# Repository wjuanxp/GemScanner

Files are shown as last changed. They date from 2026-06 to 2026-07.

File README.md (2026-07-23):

# GemScanner

A gemstone **outline scanner**. A telecentric lens and a machine-vision camera image a
backlit gemstone on a motorized rotary stage; the silhouettes captured around a full
revolution are fused into a watertight 3-D mesh by **shape-from-silhouette** (visual
hull). The result is an `.stl` you can measure, catalogue, or 3-D print.

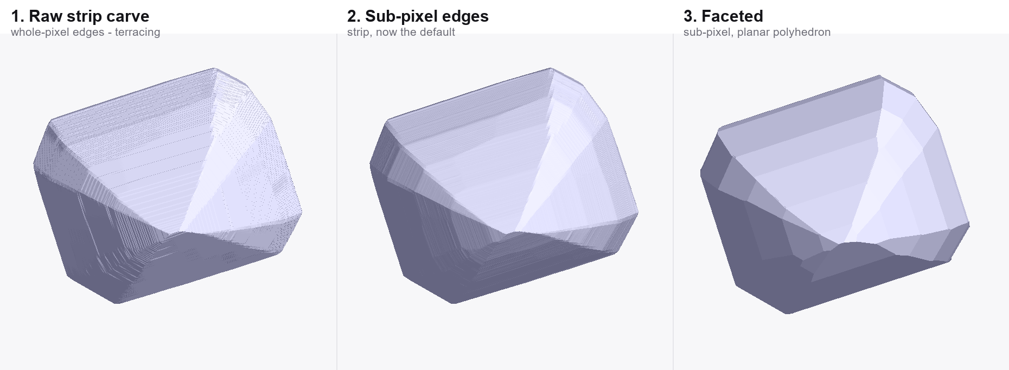
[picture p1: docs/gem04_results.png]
Three reconstructions of the same gem: raw strip carve with terracing, the sub-pixel-edge default with the terracing gone, and the faceted polyhedron


*The same gem04 scan reconstructed three ways. **Left:** the raw per-row strip carve
shows horizontal "strike line" terracing — a reconstruction artifact, not real
geometry. **Middle:** [sub-pixel edge localisation](#sub-pixel-edge-localisation)
(now the default) places each silhouette edge on its intensity crossing instead of
the nearest whole pixel, removing the artifact at its source. **Right:** the
[faceted method](#reconstruction-methods) fits the silhouettes into a watertight
planar polyhedron.*

## How it works

1. A collimated backlight makes the gem a dark silhouette against a bright field.
2. The stage rotates the gem through 360°, capturing ~180 views.
3. Each image row becomes a horizontal cross-section carved by intersecting the
   silhouette strips from every view (the visual hull).
4. The cross-sections are lofted (or marching-cubed) into a closed mesh and exported.

## Highlights

- **Pure-Python reconstruction core** — no hardware needed to reconstruct an existing
  scan or to run the full test suite (synthetic cameras stand in for the rig).
- **PySide6 GUI** — a guided per-gem wizard (mount → align → calibrate → scan →
  reconstruct) with live preview, exposure/gain control, and a reconstruction-method
  picker.
- **Selectable reconstruction methods** — trade speed for surface quality, from a fast
  raw visual hull to an anti-aliased volumetric hull (see below).
- **Faceted reconstruction** — for step-cut / faceted stones, an unsupervised
  facet-plane recovery (`method="facet"`) that fits the silhouette support function
  into a watertight polyhedron of planar facets, girdle ring included.
- **Swappable camera backends** — `gentl` (Harvesters/GenICam), `baumer` (neoAPI),
  `opencv` (USB), or `mock` — a one-line config change.
- **ESP32-C6 motion firmware** — a USB-CDC line protocol driving a 5-phase stepper
  (`firmware/`).

## Repository layout

| Path | What |
|---|---|
| `gemscanner/reconstruction/` | Visual hull, soft hull, faceted-plane fit, mesh lofting, de-terracing |
| `gemscanner/vision/` | Silhouette extraction |
| `gemscanner/gui/` | PySide6 app (wizard, preview, panels, worker thread) |
| `gemscanner/camera/` | Camera backends + factory (`gentl`/`baumer`/`opencv`/`mock`) |
| `gemscanner/motion/` | Rotary stage client speaking the firmware protocol |
| `gemscanner/acquisition/` | Step-and-settle scan controller, pre-scan FoV check |
| `gemscanner/calibration/` | Rotation-axis probing |
| `gemscanner/synthetic/`, `gemscanner/testing/` | Synthetic ellipsoid scans + fakes |
| `firmware/` | ESP-IDF ESP32-C6 motion controller (see `firmware/README.md`) |
| `docs/` | Design specs, camera notes, usage |

## Install

Targets **Python 3.12** on Windows (Open3D has no 3.13 wheel yet).

```powershell
py -3.12 -m venv .venv
.\.venv\Scripts\python -m pip install -e ".[dev]"
```

Runtime dependencies: `numpy`, `scipy`, `opencv-python`, `trimesh`, `open3d`,
`scikit-image`, `pyserial`, `pyyaml`, `harvesters`, `PySide6`. The GenTL camera backend also needs a
vendor `.cti` producer installed on the machine (e.g. Baumer's `bgapi2_gige.cti`).

## GUI

The primary interface. It reads `project.yaml` (camera backend, serial port, mm/px,
steps-per-rev, and the list of gems):

```powershell
.\.venv\Scripts\python -m gemscanner.cli gui          # or: gemscanner gui
```

Work through the left-hand wizard for each gem: **Mount → Align lighting → Holder mask
→ Calibrate axis → Scan → Reconstruct**. Pick a method in the **Reconstruction**
dropdown before clicking *Reconstruct*; the result is written to
`scans/<gem>/gem.stl`. Reconstruction reads the already-captured frames, so you can
scan once and re-reconstruct with different methods to compare.

## Reconstruction methods

The horizontal "strike lines" (terracing) sometimes seen on a raw scan are an artifact
of carving each image row independently — not real gem geometry. These options remove
them while preserving genuine facet edges (all measured on a real 17 µm/px scan):

| GUI choice | `ReconstructionParams` | What it does | Terracing¹ | Cost |
|---|---|---|---|---|
| Fast (visual hull) | *(defaults)* | Raw per-slice visual hull | baseline | fast |
| Smooth edges *(recommended)* | `edge_median_rows=9` | Median-smooths the silhouette edge per view (image space) | ≈ −80% | fast |
| Smooth surface | `axial_median_rows=9` | Median-smooths the ring radius field along z (mesh space) | ≈ −85% | fast |
| High accuracy | `method="soft_hull"` | Anti-aliased volumetric visual hull + marching cubes | ≈ −70%, sharper facets | minutes |
| Faceted gem (planar) | `method="facet"` | Fits the support function into planar facets → watertight polyhedron | n/a² | seconds |

¹ Reduction of the horizontal-band artifact on a real 17 µm/px scan; larger median
windows remove more (edge window 15 reaches ≈ −96%).

### Sub-pixel edge localisation

The options above *denoise* the terracing after the fact. `subpixel_edges`
(**on by default**; CLI: `--no-subpixel-edges` for a whole-pixel baseline, GUI:
the *Sub-pixel edges* checkbox) attacks its source instead: rather than snapping
each silhouette edge to the nearest whole column, it places the edge where that
row's intensity profile crosses the threshold, by linear interpolation between
the bracketing pixel pair. Edge position becomes continuous instead of quantised
to 17 µm, so rows whose true edges differ by a fraction of a pixel stop reporting
the same value.

Measured on `scans/gem04` (`holder_mask_rows=705`, 30 views):

| | whole-pixel | sub-pixel |
|---|---|---|
| per-row edge roughness (median \|d²edge/dz²\|) | 12.62 µm | **2.18 µm** (−83%) |
| distinct edge values per view | 217 of 378 rows | 374 of 378 rows |
| mean edge shift | — | +0.43 µm |

The shift is negligible because real backlit edges are anti-aliased and Otsu
lands mid-ramp, so the two crossings move symmetrically. (A hard *synthetic*
step has no ramp and does shift ~half a pixel per side — synthetic accuracy
figures are not comparable across the flag.) Whole-slice results move very
little: `strip` volume +0.5%, `facet` +0.04%, both still watertight; `facet`
recovers 208 → 232 planes.

On by default since the gem04 strip + facet sub-pixel meshes cleared the
`method="facet"` v2.3 visual sign-off gate. Ignored by `method="soft_hull"`,
which carves from a distance transform instead of spans.

² The faceted method doesn't carve per-slice rings, so terracing doesn't arise — it
recovers the facet planes directly.

Edge/axial median use rank-rejection of per-row outliers, so facets stay crisp;
measured impact on volume is ≤ +0.24% and on bounding dimensions effectively zero.
The soft hull is the most accurate (synthetic-ellipsoid volume error −0.8% vs −2.7%
for the raw hull) and produces a watertight single-body mesh; it requires
`scikit-image`.

The **faceted** method is for genuinely faceted stones (step cuts, brilliants). Instead
of carving cross-sections it detects each facet's azimuth from the slice-polygon edges,
segments the per-view support function `H(z)` into planar tiers, recovers the girdle
band, and assembles the resulting half-spaces into a single watertight polyhedron of
flat facets — in seconds, with no soft-hull seed. On the gem04 reference scan it
recovers 56 facets (including the faceted girdle ring) at 5 µm median per-facet fit,
with bounding-box extents within 16/40/77 µm (X/Y/Z) of the visual-hull mesh. It is
best on clean step/brilliant cuts; rounded cabochons should use one of the hull methods.
Requires `scipy`.

## CLI

```powershell
# Reconstruct a mesh from an existing scan dataset (no hardware)
.\.venv\Scripts\python -m gemscanner.cli reconstruct scans\gem01 -o gem.stl

# Choose the method, mask the pedestal rows, and use sub-pixel edges
# (this is the gem04 faceted recipe as a one-liner)
.\.venv\Scripts\python -m gemscanner.cli reconstruct scans\gem04 -o gem.stl `
    --method facet --holder-mask-rows 705 --subpixel-edges

# View a mesh in an interactive Open3D window
.\.venv\Scripts\python -m gemscanner.cli view gem.stl

# Full bench scan: config -> prescan -> capture 360 deg -> reconstruct -> gem.stl
.\.venv\Scripts\python -m gemscanner.cli scan -c config.example.yaml -o scans\gem01
```

## Configuration

`config.example.yaml` (for the `scan` CLI) and `project.yaml` (for the GUI) select the
camera backend, serial port, scan parameters, and calibration file. For the legacy
Baumer EXG50 GigE camera use `camera_backend: gentl` with a `cti_path` to a GenTL
producer; neoAPI (`baumer`) only supports the newer CX/X families. Swapping to a USB
camera is a one-line change to `opencv`.

## Tests

```powershell
.\.venv\Scripts\python -m pytest -q
```

All orchestration, protocol, reconstruction, and GUI logic is host-tested in-process
via `FakeFirmware` (the firmware protocol contract), `MockCamera`, and `SceneCamera`
(which links the fake motion angle to a rendered ellipsoid silhouette). Real serial
I/O, the OpenCV/Baumer/GenTL cameras, and the Open3D window are **bench-verified** on
hardware.

## Bench bring-up

With the camera and collimated backlight aligned, the stage/driver/ESP32 powered, and a
`calibration.json` (axis column, mm/px, steps-per-rev) produced from the calibration
routines, run the GUI wizard or the `scan` CLI. The pre-scan FoV check aborts (naming
the clipping angle) if the gem leaves the frame at any rotation; otherwise it captures
the revolution, reconstructs, and writes a watertight `gem.stl`. Compare the
bounding-box extents against caliper measurements within the calibrated tolerance.

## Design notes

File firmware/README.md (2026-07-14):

# GemScanner Firmware (ESP32-C6)

Motion-control firmware for the gemstone outline scanner. Runs on a **Waveshare
ESP32-C6-LCD-1.47** and drives the SURUGA SEIKI KRW06360 rotary stage (Oriental
Motor 5-phase stepper via an **ADB-5331A** driver) under a line-based USB-CDC
command protocol, so the host PC can run step-and-settle scans.

Built with **ESP-IDF 5.4**.

## Architecture

Pure logic is isolated from hardware so it can be unit-tested on a PC:

| Path | Responsibility | Tested |
|---|---|---|
| `components/command_parser` | ASCII line → `command_t` | host (gcc/ctest) |
| `components/motion_math` | degrees↔microsteps, angle wrap | host |
| `components/ramp` | trapezoidal step-interval planner | host |
| `components/fmt_num` | integer → comma-grouped string (`35,000`) | host |
| `main/stepper.c` | GPTimer STEP/DIR pulse generation w/ ramp | bench |
| `main/usb_cdc.c` | USB Serial/JTAG line read/write | bench |
| `main/controller.c` | command dispatch + state machine | bench |
| `main/status_display.c` | RGB LED + ST7789 LCD (LVGL) status | bench |
| `main/app_main.c` | init order + run loop | bench |

These `components/*` modules contain **no ESP-IDF headers** and are compiled
both into the firmware and into the host test harness (`host_test/`).

## Command protocol

Line-based ASCII, terminated by `\n`, `\r`, or `\r\n`. Replies are `\n`-terminated.
A move command replies `OK` immediately, then `READY` after the move completes and
the settle delay elapses.

| Command | Meaning | Immediate | Deferred |
|---|---|---|---|
| `STEP <n>` | move `n` microsteps, signed (+ = DIR active) | `OK` | `READY` |
| `MOVEDEG <x>` | move `x` degrees (float) | `OK` / `ERR nores` | `READY` |
| `SETV <v>` | max speed, microsteps/s (>0) | `OK` / `ERR badarg` | — |
| `SETACC <a>` | acceleration, microsteps/s² (>0) | `OK` / `ERR badarg` | — |
| `SETSETTLE <ms>` | settle delay, ms (≥0) | `OK` / `ERR badarg` | — |
| `SETRES <n>` | microsteps per 360° (>0) | `OK` / `ERR badarg` | — |
| `HOME` | zero the logical angle (no motion) | `OK` | `READY` |
| `STATUS` | query | `STATUS angle=<deg> steps=<n> state=idle v=<> a=<> settle=<ms> res=<n>` | — |

Unknown verb → `ERR unknown`. Bad/missing argument → `ERR badarg`.

**`steps-per-360°` is never hardcoded.** It is `motor step angle × driver microstep ×
stage gear ratio` and must be sent at runtime with `SETRES` (the PC calibrates it).
Until `SETRES` is sent, `MOVEDEG` returns `ERR nores` and the reported/displayed
`angle` stays `0.00` (steps still track).

Defaults at boot: `v=4000`, `a=20000`, `settle=150`, `res=0`, `pos=0`.

## Wiring

### Stepper driver (1-pulse mode)
The ADB-5331A must be set to **1-pulse mode** (PULSE + DIRECTION). Its inputs are
opto-isolated and expect ~5 V, so drive them through a **3.3 V → 5 V buffer /
level-shifter** — do not wire the ESP32 GPIOs straight into the driver.

| ESP32-C6 | Signal | → buffer → ADB-5331A |
|---|---|---|
| GPIO1 | STEP (pulse) | PULSE+ |
| GPIO2 | DIR | DIR+ |
| GPIO3 | ENABLE | AWO/ENABLE+ |
| GND | common | input commons |

Active levels and the STEP pulse width are in `main/pins.h` (`DIR_ACTIVE_LEVEL`,
`ENABLE_ACTIVE_LEVEL`, `STEP_PULSE_US`). Verify the driver's input current-limit
resistor and minimum pulse width against the ADB-5331A datasheet. (HOME has no
sensor yet — it only zeroes the logical angle.)

### On-board peripherals (no external wiring)

Both indicators share one **per-state palette** so they always agree. The state
is one of four values (`disp_state_t`); the LCD shows a friendlier word for each:

| State (`disp_state_t`) | LCD word | Accent colour | Meaning |
|---|---|---|---|
| `ST_DISCONNECTED` | **OFFLINE** | muted blue `#5A6B8C` | no host link |
| `ST_IDLE` | **READY** | green `#22C55E` | waiting for a command |
| `ST_MOVING` | **ROTATING** | amber `#F5A623` | stage in motion |
| `ST_SETTLING` | **SETTLING** | cyan `#22D3EE` | holding to stabilise |

(The USB `STATUS` reply is separate and still reports `state=idle`; the words
above are display-only.)

- **RGB LED** (WS2812, GPIO8): lit in the accent colour of the current state
  (blue / green / amber / cyan above), dimmed for comfortable brightness. *Note:*
  this board's LED takes **RGB** order while `led_strip`'s WS2812 model emits GRB,
  so `led_set()` swaps R↔G.
- **LCD** (ST7789, 172×320, SPI: MOSI=6 SCLK=7 CS=14 DC=15 RST=21, backlight=22):
  a minimalist **dark-theme** status screen (`status_display.c`) — a full-width
  accent bar and dot at the top, the large colour-coded **state word** (hero), a
  hairline divider, then `angle` (`142.50°`) and comma-grouped `steps` (`35,000`)
  as value + caption pairs, centred on the near-black canvas. Uses the Montserrat
  20/28 fonts (enabled in `sdkconfig.defaults`; 14 is on by default). Three
  settings were needed for this panel: `swap_bytes = true` (RGB565 byte order —
  without it text shows a colour fringe), `esp_lcd_panel_set_gap(panel, 34, 0)`
  (the 172-wide panel's RAM offset), and the backlight on **GPIO22 via LEDC PWM**
  at `LCD_BL_DUTY_PCT` (default 50%).

## Build, flash, monitor

Activate ESP-IDF 5.4 first (this install lives at `D:\ESP32`):

```powershell
& 'D:\ESP32\idf\v5.4\esp-idf\export.ps1'
cd 'D:\CodingProject\GemScanner\firmware'
idf.py set-target esp32c6     # once
idf.py build
idf.py -p COMx flash monitor  # COMx = the board's port; Ctrl+] exits monitor
```

The first build downloads the managed components (`lvgl 9.3`, `esp_lvgl_port 2.8`,
`led_strip 2.5`) — it needs network and is slower.

### Talking to it
In `idf.py monitor` there is **no local echo** — you won't see what you type, only
the board's replies. Press Enter (sends CR; the firmware accepts CR/LF/CRLF). Try:

```
SETRES 50000
STATUS
STEP 12500      → OK … READY  (stage turns ~90° if res≈50000)
MOVEDEG 45      → OK … READY
```

If replies are garbled by interleaved log bytes, set the console off USB:
`idf.py menuconfig → Component config → ESP System Settings → Channel for console
output → None` (or UART0), then rebuild — the protocol then owns the USB link.

## Host unit tests (no hardware)

```bash
cd firmware/host_test
cmake -S . -B build -G Ninja
cmake --build build
ctest --test-dir build --output-on-failure
```

Covers `command_parser`, `motion_math`, `ramp`, and `fmt_num`.

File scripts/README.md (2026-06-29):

# Bench scripts

Guided bring-up / calibration scripts. Run each from the repo root with the venv:

```powershell
.venv\Scripts\python.exe scripts\<name>.py --help
```

They all read `config.example.yaml` (`-c` to override) and read/write the
`calibration.json` named by `calibration_path` in that config.

## Recommended order

1. **Motion** — confirm the stage turns:
   ```powershell
   .venv\Scripts\python.exe scripts\smoke_motion.py --res 50000
   ```
2. **Camera** — grab a frame, eyeball exposure:
   ```powershell
   .venv\Scripts\python.exe scripts\grab.py -e 470000 -o grab.png ; Invoke-Item grab.png
   ```
3. **steps_per_rev** — empirical is most reliable (command N steps, measure degrees):
   ```powershell
   .venv\Scripts\python.exe scripts\calibrate_steps.py --empirical 50000 360
   # or directly:        --value 50000
   # or computed:        --compute 500 10 18     (motorSteps microstep gear)
   ```
4. **mm_per_px** — from a gauge of known length imaged by the camera:
   ```powershell
   .venv\Scripts\python.exe scripts\calibrate_scale.py --px 1000 --mm 28.8 --write
   ```
5. **axis_column** — fit the rotation axis from silhouette centroids:
   ```powershell
   .venv\Scripts\python.exe scripts\calibrate_axis.py -n 12 --write
   ```
6. **FoV check** — confirm the gem never clips over a revolution:
   ```powershell
   .venv\Scripts\python.exe scripts\check_fov.py -n 12
   ```

After 3-5, `calibration.json` holds `steps_per_rev`, `mm_per_px`, `axis_column`
(+ `axis_tilt_rad=0`, `eccentricity_mm`). Then run the full pipeline:

```powershell
.venv\Scripts\python.exe -m gemscanner.cli scan -c config.example.yaml -o scans\gem01
.venv\Scripts\python.exe -m gemscanner.cli view scans\gem01\gem.stl
```

## Notes
- Only one app can hold the GigE camera at once - close Camera Explorer before running these.
- `calibrate_steps`/`calibrate_scale`/`calibrate_axis` use `--write` to persist into
  `calibration.json`; without it they just print the value.
- Long camera exposure (e.g. 470 ms with no dedicated light) makes scans slow; lower it
  once the collimated backlight is installed.

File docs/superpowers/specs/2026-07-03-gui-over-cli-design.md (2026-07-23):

# GemScanner GUI — Design Spec

**Date:** 2026-07-03
**Status:** Approved (brainstorming), pending implementation plan
**Depends on:** Plan A (reconstruction core), Plan B (firmware), Plan C (hardware integration) — all merged to `main` and bench-verified 2026-07-03.

## 1. Purpose & Scope

A PySide6 desktop application that turns the current edit-YAML-and-rerun-scripts workflow into an
interactive, guided process. The headline capabilities the user asked for:

- **Live lighting/alignment preview** — see the camera frame while positioning the gem and backlight.
- **Interactive exposure/gain tuning** — adjust and see the effect immediately.
- **Easier batch scanning** — a guided queue of gems, one operator loop.

The GUI **wraps** existing library code. It does not reimplement reconstruction, calibration, or scan
orchestration. The existing `reconstruct` / `view` / `scan` CLI commands and the `scripts/` bring-up
tools remain fully working; the GUI is additive.

### Out of scope (YAGNI)

- Scan-history database or re-scan browser.
- Multi-user / remote / web access.
- A camera streaming API — live preview is polled `grab()`.
- Changes to the unused `OpenCvCamera.grab` / neoAPI `BaumerCamera` paths.

## 2. Architecture — Three Layers

### a. Service layer (Qt-free, unit-testable) — `gemscanner/gui/session.py`

A `ScanSession` owns exactly one opened camera and one stage, and exposes coarse operations that reuse
existing code:

- `grab()` — one frame.
- `analyze_frame(frame, threshold, holder_mask_rows)` — returns silhouette mask + `min/max/mean` +
  intensity histogram + FoV/eccentricity status. Built on existing `vision.silhouette.extract_silhouette`
  and `acquisition.prescan`.
- `calibrate_axis(n_probe, progress, cancel)` — rotates a revolution, fits `axis_column`.
- `run_scan(params, progress, cancel)` — drives the scan, writes the dataset.
- `reconstruct(out_dir, holder_mask_rows, smooth, method, edge_median_rows, axial_median_rows, subpixel_edges)`
  — builds + smooths the mesh, returns watertight/extents. `subpixel_edges` (default `True`, added
  2026-07-23) places each silhouette edge on its intensity crossing instead of the nearest whole pixel.

This layer has no Qt imports and is fully testable headless with `MockCamera` / `SceneCamera` +
`FakeFirmware`.

### b. Project model — `gemscanner/gui/project.py`

Dataclasses:

- `GemJob`: `name`, `holder_mask_rows`, `axis_column`, optional `exposure_us` / `gain` overrides,
  `out` (output dir).
- `Project`: shared camera settings + serial config + project-level `mm_per_px` and `steps_per_rev`
  (these carry across gems on the same pedestal/motor), plus an ordered `gems: [GemJob, ...]` list.

Load/save to `project.yaml`, which is a **superset of the current `ScannerConfig` schema**. A single-gem
project therefore remains runnable by the existing `scan` CLI, and `calibration.json` semantics are
preserved.

### c. Qt UI layer — `gemscanner/gui/app.py` + widgets

- `LivePreviewWidget` — a `QGraphicsView` showing the frame with overlays:
  - Silhouette (Otsu-threshold) tint, so the operator sees exactly what reconstruction will "see"
    (reveals refracted-light leak holes, edge blur, uneven backlight). Threshold selectable Otsu/manual.
  - Draggable horizontal **holder-mask line**; everything below is greyed. Sets `holder_mask_rows`.
  - **FoV/eccentricity warning** — red when the silhouette touches an image border or is badly off
    the calibrated axis; green "ready to scan" when clear.
  - **Exposure stats + histogram** panel — live `min/max/mean` and an intensity histogram to confirm
    the gem hits ~0 and the background is bright/uniform.
- `WizardPanel` — the per-gem step sequence (Section 5).
- `QueuePanel` — add / remove / reorder gems.
- `ReconstructionPanel` — how the mesh is built from the silhouettes:
  - A method-preset combo (Fast strip hull / Smooth edges / Smooth surface / High accuracy soft-hull /
    Faceted gem), each mapping to reconstruction kwargs.
  - A **Sub-pixel edges** checkbox (added 2026-07-23, **default checked**) — orthogonal to the preset:
    it applies to the strip and facet methods (soft-hull ignores it), so it sets `subpixel_edges` in
    `selected_kwargs()` independently of the combo choice. `set_subpixel_edges(on)` toggles it and it is
    threaded `ReconstructionPanel → main_window → worker._op_reconstruct → session.reconstruct`.

### Visual style

Modern minimalism with a **dark theme**. Applied via a single Qt stylesheet (QSS) loaded at startup —
no per-widget inline styling. Guidelines:

- Dark neutral background (near-black / dark grey), low-chroma surfaces, one restrained accent color for
  primary actions and the "ready to scan" state.
- Generous spacing, flat controls (no heavy bevels/gradients), minimal borders — separation by spacing
  and subtle surface elevation rather than lines.
- The live preview is the visual focus: the frame sits on the darkest surface so the bright backlit
  silhouette carries the contrast; overlays (silhouette tint, mask line, FoV state) use the accent and a
  warning color sparingly.
- One clean sans-serif type scale; status/stats in a monospace face for legibility of `min/max/mean`.

Style lives in `gemscanner/gui/style.qss` so it can be tweaked without touching widget code.

## 3. Threading

The primary implementation risk. A **single `HardwareWorker` `QThread` is the only owner of the camera
and stage** — this mirrors the physical constraint that only one consumer can hold the GigE camera (and
the single serial port). The UI thread posts commands; the worker executes and emits Qt signals
(`frame_ready`, `progress`, `done`, `error`).

- **Live preview** = the worker polling `grab()` in a loop while idle, downscaling for display, emitting
  at whatever rate the 5 MP EXG50 sustains (a few fps is fine for alignment). It **auto-pauses** during
  moves, scans, and calibration because those run on the same single thread.
- **Cancellation** = a flag checked between scan views and between calibration probes.

No `CameraBackend` change is needed; polled preview works with `MockCamera` / `SceneCamera` for
hardware-free development and testing.

## 4. Required Refactor (small, removes duplication)

- Extract the axis-fit probe loop currently inline in `scripts/calibrate_axis.py:main` into
  `gemscanner/calibration/axis_probe.py` as a callable function with `progress` and `cancel` hooks.
- Add `progress` and `cancel` hooks to `ScanController.run` in
  `gemscanner/acquisition/scan_controller.py`.

`scripts/calibrate_axis.py` and the GUI then call the same `axis_probe` function; the scan path is shared
too. `run_scan_from_config` stays as the CLI entry point, but the GUI drives the finer-grained steps
directly since it already holds the camera and stage open.

## 5. Guided Wizard Flow (per gem)

0. **Connect** (once per session): choose project file, camera backend / exposure / gain, COM port →
   connect; live preview starts.
1. **Mount** — prompt operator to mount the gem → confirm.
2. **Align** — live preview + exposure/gain sliders + histogram. Tune until the gem is solid black
   (`min≈0`), the background is bright and uniform, the silhouette overlay is solid (no leak holes), and
   the FoV indicator is green.
3. **Holder mask** — drag the mask line to the gem/pedestal junction → `holder_mask_rows`.
4. **Calibrate axis** — [Run] rotates one revolution over `n_probe` steps, fits `axis_column`, shows the
   centroid-swing amplitude, with live progress. Writes into the gem's calibration.
5. **Scan** — runs `n_views` with a progress bar and cancel; the preview updates per view.
6. **Reconstruct + smooth** — builds the mesh, reports watertight + extents; [View] opens the Open3D
   viewer in a background window (offscreen render is unavailable on this machine — no EGL headless).
7. **Advance** — prompt "swap to `<next gem>`" → loop back to step 1 for the next queued gem.

## 6. Persistence

`project.yaml`, a superset of the current config schema:

```yaml
camera_backend: gentl
camera: { cti_path: ..., exposure_us: 500, gain: 5, pixel_format: Mono8 }
serial_port: COM3
serial_baud: 115200
mm_per_px: 0.0170          # project-level; carries across gems on the same pedestal/motor
steps_per_rev: 90000       # project-level
gems:
  - name: ruby-01
    holder_mask_rows: 660
    axis_column: 1214
    out: scans/ruby-01
    # optional per-gem exposure_us / gain overrides
  - name: emerald-02
    holder_mask_rows: 705
    axis_column: 1216
    out: scans/emerald-02
```

The GUI reads and writes this file. `calibration.json` semantics (axis_column / mm_per_px /
steps_per_rev / axis_tilt_rad) are preserved for CLI compatibility.

## 7. Error Handling

- Camera-open failure (e.g. GigE camera still held by Baumer Camera Explorer `bexplorer`) → clear
  non-fatal dialog telling the operator to close the other app.
- `StageError` timeouts → non-fatal dialog; the ESP32 reset-on-serial-open quirk is already handled by
  `SerialTransport` (settle + flush after open, fix `a1cba1f`).
- FoV-clip failure at the Scan step blocks scanning with an explicit message ("silhouette clips; re-seat
  the gem").
- Cancel stops between views and leaves the partial dataset flagged.

## 8. Testing

- Service layer (`ScanSession`) and project model (`Project` / `GemJob` load/save) unit-tested headless
  with `MockCamera` / `SceneCamera` + `FakeFirmware`, extending the existing 53-test suite.
- The end-to-end mock scan→reconstruct path (via `SceneCamera`) is reused to test `run_scan` /
  `reconstruct` wiring through the session.
- UI kept thin — logic lives in the tested service layer. Optional `pytest-qt` smoke test for widget
  construction and the mask-line → `holder_mask_rows` binding.

## 9. Dependencies

- New: **PySide6** (Qt for Python). Optional dev dep: `pytest-qt`.
- Existing venv is Python 3.12 (open3d has no 3.13 wheel) — PySide6 has 3.12 wheels.

## 10. Open Questions / Deferred

None blocking. Deferred to future work: scan history, unattended multi-gem (blocked by the physical swap
requirement anyway), and finishing/removing the unused OpenCV/neoAPI camera backends.

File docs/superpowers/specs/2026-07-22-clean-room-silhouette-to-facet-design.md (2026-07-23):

# Clean-room silhouette → faceted-gemstone investigation

Date: 2026-07-22. Scope: a fresh, independent investigation of the
silhouette → faceted-convex-polytope reconstruction problem, run as a
survey-then-bake-off on the gem04 real scan. This is deliberately a
clean-room exercise: the shipped `method="facet"` (v2.3) pipeline is set
aside as a **benchmark to match/beat**, not reused or extended.

## Why this exists

The shipped v2.3 facet pipeline is already merged, signed off on gem04
(56 planes, watertight, 5 µm median facet RMS, extents X+16 / Y+40 / Z+77 µm
vs `gem.stl`) and is structurally free of horizontal strike-lines. The user
asked for a **clean-room investigation** anyway: re-derive the problem from
first principles, survey the method families the literature offers, and
empirically bake off the most promising ones on the real gem04 frames — to
learn whether an independent approach matches, beats, or teaches us something
the shipped one does not (notably the residual Z +77 µm extent gap).

## The data (gem04)

- 180 backlit silhouettes, 2° turntable steps, full 360°.
- **Orthographic** projection (confirmed: `coords.column_to_projection` is a
  pure linear `mm_per_px` scale, no perspective divide). This is the linchpin
  assumption for the entire support-function / dual-convex framework.
- Known calibration: `mm_per_px`, per-row `axis_column` (+ small `axis_tilt`),
  per-frame angle. `holder_mask_rows = 705` masks the pedestal post (rig
  calibration for this mount; not carried in the manifest — supplied
  explicitly, as in `scripts/validate_facet_gem04.py`).
- Reference: `scans/gem04/gem.stl` (dimensional ground truth).
  **[Superseded by the results note §6: gem.stl is NOT independent ground
  truth — it is a Taubin-smoothed strip reconstruction of this same scan.]**

## The target and the key representation

A cut gem is, to excellent approximation, a **convex polytope** — an
intersection of a few dozen half-spaces (table, crown mains/stars, girdle
facets, pavilion mains, culet). By Minkowski's theorem a convex body is
uniquely determined by its **support function**; a *faceted* convex body has a
**piecewise-affine** support function, each facet being one linear piece.

Under orthographic projection, each silhouette's left/right edge at image row
*v* (→ height *z*) and view angle *θ* is a true **support value** of the
height-*z* cross-section:

```
h(θ, z) = max_{(x,y) ∈ slice(z)} ( x·cosθ − y·sinθ )
```

Stacked over all θ and z, `h(θ, z)` is the shared clean-room input
representation all candidates consume. (This mirrors the shipped
`SupportMaps.h_right/h_left`, but is rebuilt independently in the harness so
the investigation stays clean-room from the silhouettes up.)

## Root cause of horizontal strike-lines (the sorting axis)

A horizontal strike-line is a **z-to-z inconsistency**: consecutive height
rows land at radii that disagree by noise ε because each row was decided from
its own silhouette edges *independently*. Space-carving and per-slice visual
hull do exactly this — every z-layer is an independent 2D decision, so
silhouette edge noise is written straight into a horizontal ridge.

> **Principle that eliminates strike-lines:** never fix a surface point from a
> single row in isolation. Any method that fits a model spanning *z* — an
> affine support piece, a global plane, a parametric cut, an implicit surface —
> averages per-row noise into the fit and has no per-row degree of freedom
> left to strike. Every family below is sorted on this one axis.

## Survey of method families

| # | Family | Core idea | Strike-line-prone? | Fit for this rig |
|---|---|---|:---:|---|
| 1 | Space carving / per-slice visual hull | Intersect back-projected silhouette cones on a voxel/slice grid | **Yes** (each layer independent) | The known failure; keep only as negative control |
| 2 | Support-function half-space fitting | Detect facet directions, fit affine `h(θ,z)=β+αz` per facet, intersect half-spaces | No (planes span all z) | The shipped v2.3; strong fit — the benchmark |
| 3 | Dual-space convex reconstruction | Each tangent plane = a point in polar-dual space; body = polar dual of dual-point hull; merge near-coplanar faces | No (global convex hull) | Elegant, nearly parameter-free, exploits convexity directly |
| 4 | Tangent-plane RANSAC | Every (edge point, local tangent) votes a plane hypothesis; RANSAC/cluster in plane-parameter space | No (planes global) | Robust, standard, assumption-light |
| 5 | EGI / Minkowski (normals + areas) | Cluster tangent normals on the Gauss sphere → facet normals, then solve offsets | No | Clean for convex polytopes; offset solve is fiddly |
| 6 | Parametric cut template | Fit a known brilliant/step-cut model to silhouettes | No | Robust *if* cut known; fails on irregular cuts — too specific |
| 7 | Differentiable silhouette rendering (SDF/mesh + planarity prior) | Optimize a surface so rendered silhouettes match, regularized to planarity | No | Modern but disproportionate to a benchtop tool — future work |

Families 2/3/4/5 are the strike-line-free, convexity-exploiting contenders.
Family 1 is the negative control. Families 6 and 7 are out of scope (too
cut-specific / disproportionate) but recorded for completeness.

## The three candidates (bake-off set)

All three consume the same clean-room `h(θ, z)` support samples and produce a
mesh independently; none imports `gemscanner/reconstruction/`.

- **Cand-A — Tangent-plane RANSAC (family 4).** Each silhouette edge point +
  local tangent → a candidate 3D plane; RANSAC / cluster in (normal, offset)
  space; intersect the winning half-spaces into a polytope. Most general,
  outlier-robust, assumption-light.
- **Cand-B — Dual-space convex reconstruction (family 3).** Convert all
  tangent planes to dual points, take their convex hull, dualize back to the
  polytope, merge near-coplanar faces into facets. Nearly parameter-free; the
  cleanest expression of "the gem is convex."
- **Cand-C — EGI / Gauss-sphere clustering (family 5).** Cluster tangent
  normals on the sphere to get facet *directions* first, then solve each
  offset from its support samples. Tests whether direction-first beats
  point/plane-first.

**Negative control:** space-carving on the same data, to reproduce
strike-lines and confirm A/B/C are free of them in the side-by-side render.

**Benchmark (not a candidate):** the shipped v2.3 facet output
(56 planes; X+16 / Y+40 / Z+77 µm; 5 µm RMS) — the bar to match/beat.

## Shared harness & success criteria

One harness loads gem04 (`holder_mask_rows=705`), builds the clean-room
`h(θ, z)`, and runs each candidate + control + the v2.3 benchmark, reporting
per method:

- **Numeric gates** (reuse `validate_facet_gem04.py`'s structure): facet
  count, watertight, extents vs `gem.stl` (µm/axis), volume delta, per-facet
  RMS median/max.
- **Strike-line metric (new, objective):** high-pass energy of the final
  surface radius along z at fixed azimuth (row-to-row radius variance after
  removing the facet's affine trend). Space-carving scores high; A/B/C should
  be near zero. This makes "strike-line-free" measurable, not just visual.
- **Visual gate (mandatory, per project memory):** render all methods +
  `gem.stl` side-by-side into one comparison image for user sign-off.

**Success** = a candidate that is (a) watertight, (b) objectively and visually
strike-line-free, (c) within a small factor of v2.3 on extents/RMS, and
ideally teaches something new (e.g. Cand-B closing the Z +77 µm gap, or
reaching parity with far fewer tuned parameters).

## Deliverables

1. This design doc (committed).
2. A results note under `docs/superpowers/notes/` — survey + bake-off table +
   verdict + recommendation.
3. Prototype code under `scratchpad/` only (clean-room; does **not** touch
   `gemscanner/reconstruction/`), plus one side-by-side comparison render.
4. A recommendation: adopt-as-is / port one idea into the shipped pipeline /
   v2.3 remains best.

## Explicit non-goals

- No changes to `gemscanner/reconstruction/` in this investigation (any
  adoption is a separate, later task gated on the recommendation).
- Not solving perspective/telecentric calibration — orthographic is given.
- Not the parametric-template or differentiable-rendering families (recorded,
  deferred).
- gem04 is the single test subject; broader multi-scan validation is future
  work (consistent with the v2.3 sign-off caveat).

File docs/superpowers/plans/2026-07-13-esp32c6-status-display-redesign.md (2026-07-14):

# ESP32-C6 Status Display Redesign Implementation Plan

> **For agentic workers:** REQUIRED SUB-SKILL: Use superpowers:subagent-driven-development (recommended) or superpowers:executing-plans to implement this plan task-by-task. Steps use checkbox (`- [ ]`) syntax for tracking.

**Goal:** Replace the ESP32-C6 LCD's three plain top-left text labels with a minimalist dark-theme screen built around a large, color-coded state word, and re-tune the onboard RGB LED to the same palette.

**Architecture:** All rendering lives in `firmware/main/status_display.c` (LVGL 9.x via `esp_lvgl_port`). The `status_display_set(state, angle, steps)` signature and its `controller.c` call sites are unchanged — only the LVGL object graph, styling, per-state palette, and LED hues change. A small pure `fmt_num` component provides comma-grouped integer formatting so the steps value reads as `35,000`; it is host-tested because it has separable logic.

**Tech Stack:** ESP-IDF (target esp32c6), LVGL 9.x, `esp_lvgl_port`, `led_strip` (WS2812), ST7789 over SPI. Host tests use the existing `firmware/host_test` minunit harness.

## Global Constraints

- Target: `esp32c6` (`CONFIG_IDF_TARGET="esp32c6"`).
- Display is ST7789 **172 wide × 320 tall**, portrait; do not change `lcd_init()` hardware setup (SPI bus, panel config, gap, backlight, byte-swap).
- Public API is frozen: `status_display_set(disp_state_t state, double angle_deg, long steps)` and `status_display_init(void)` keep their exact signatures; `disp_state_t` enum values stay `ST_DISCONNECTED, ST_IDLE, ST_MOVING, ST_SETTLING`. No changes to `controller.c` or `status_display.h`.
- No new data surfaced on screen (no speed/accel/settle/res).
- All LVGL widget mutation happens under `lvgl_port_lock(50)` / `lvgl_port_unlock()`; on lock timeout, `ESP_LOGW` and skip the frame. The LED update stays outside the lock.
- State word → color mapping (accent hex / displayed word / LED r,g,b intent):
  - `ST_DISCONNECTED` → "OFFLINE" → `#5A6B8C` → LED (10,14,24)
  - `ST_IDLE`         → "READY"   → `#22C55E` → LED (0,34,12)
  - `ST_MOVING`       → "ROTATING"→ `#F5A623` → LED (40,22,0)
  - `ST_SETTLING`     → "SETTLING"→ `#22D3EE` → LED (0,28,28)
- Background `#0B0C0E`; value text near-white `#E8EAED`; captions/divider grey `#8A9099` / `#2A2D31`.

---

## File Structure

- Create: `firmware/components/fmt_num/include/fmt_num.h` — declares `fmt_thousands`.
- Create: `firmware/components/fmt_num/fmt_num.c` — comma-grouping formatter.
- Create: `firmware/components/fmt_num/CMakeLists.txt` — IDF component registration.
- Create: `firmware/host_test/test_fmt_num.c` — minunit tests for the formatter.
- Modify: `firmware/host_test/CMakeLists.txt` — register the new host test.
- Modify: `firmware/main/CMakeLists.txt` — add `fmt_num` to `REQUIRES`.
- Modify: `firmware/sdkconfig.defaults` — enable Montserrat 20 and 28.
- Modify: `firmware/main/status_display.c` — new layout, palette, LED hues, formatter use.

---

## Task 1: `fmt_num` comma-grouping formatter (pure, host-tested)

**Files:**
- Create: `firmware/components/fmt_num/include/fmt_num.h`
- Create: `firmware/components/fmt_num/fmt_num.c`
- Create: `firmware/components/fmt_num/CMakeLists.txt`
- Test: `firmware/host_test/test_fmt_num.c`
- Modify: `firmware/host_test/CMakeLists.txt:33` (append new `add_pure_test`)

**Interfaces:**
- Consumes: nothing (pure C, `<stddef.h>` only).
- Produces: `size_t fmt_thousands(long value, char *out, size_t n);` — writes `value` into `out` (max `n` bytes incl. NUL) with `,` thousands separators and a leading `-` for negatives; returns the full formatted length (excluding NUL) even if truncated. Consumed by Task 2.

- [ ] **Step 1: Write the failing test**

Create `firmware/host_test/test_fmt_num.c`:

```c
// firmware/host_test/test_fmt_num.c
#include "minunit.h"
#include "fmt_num.h"
#include <string.h>

static char buf[32];

MU_TEST(groups_basic) {
    fmt_thousands(0, buf, sizeof(buf));        mu_check(strcmp(buf, "0") == 0);
    fmt_thousands(999, buf, sizeof(buf));      mu_check(strcmp(buf, "999") == 0);
    fmt_thousands(1000, buf, sizeof(buf));     mu_check(strcmp(buf, "1,000") == 0);
    fmt_thousands(35000, buf, sizeof(buf));    mu_check(strcmp(buf, "35,000") == 0);
    fmt_thousands(1234567, buf, sizeof(buf));  mu_check(strcmp(buf, "1,234,567") == 0);
}
MU_TEST(negatives) {
    fmt_thousands(-35000, buf, sizeof(buf));   mu_check(strcmp(buf, "-35,000") == 0);
    fmt_thousands(-1, buf, sizeof(buf));       mu_check(strcmp(buf, "-1") == 0);
}
MU_TEST(returns_full_len_and_truncates) {
    size_t n = fmt_thousands(1234567, buf, sizeof(buf));
    mu_assert_int_eq(9, (int)n);               // "1,234,567"
    char small[4];
    size_t n2 = fmt_thousands(1234567, small, sizeof(small)); // fits "1,2" + NUL
    mu_assert_int_eq(9, (int)n2);              // full length still reported
    mu_check(strcmp(small, "1,2") == 0);       // truncated, NUL-terminated
}
MU_TEST_SUITE(fmt_suite) {
    MU_RUN_TEST(groups_basic);
    MU_RUN_TEST(negatives);
    MU_RUN_TEST(returns_full_len_and_truncates);
}
int main(void) { MU_RUN_SUITE(fmt_suite); MU_REPORT(); return MU_EXIT_CODE; }
```

Create the header `firmware/components/fmt_num/include/fmt_num.h`:

```c
// firmware/components/fmt_num/include/fmt_num.h
#pragma once
#include <stddef.h>

// Format `value` with comma thousands-separators into `out` (<= n bytes incl NUL).
// Returns the full formatted length (excluding NUL), even when truncated.
size_t fmt_thousands(long value, char *out, size_t n);
```

Register the test — append to `firmware/host_test/CMakeLists.txt` after the `test_ramp` block (line 33):

```cmake
add_pure_test(test_fmt_num fmt_num
  ${COMPONENTS_DIR}/fmt_num/fmt_num.c
  test_fmt_num.c)
```

- [ ] **Step 2: Run test to verify it fails**

Run:
```bash
cmake -S firmware/host_test -B firmware/host_test/build
cmake --build firmware/host_test/build --target test_fmt_num
```
Expected: FAIL — link error `undefined reference to 'fmt_thousands'` (the `.c` is empty/absent).

- [ ] **Step 3: Write minimal implementation**

Create `firmware/components/fmt_num/fmt_num.c`:

```c
// firmware/components/fmt_num/fmt_num.c
#include "fmt_num.h"
#include <string.h>

size_t fmt_thousands(long value, char *out, size_t n) {
    int neg = value < 0;
    // Negate safely without overflowing LONG_MIN.
    unsigned long uv = neg ? (unsigned long)(-(value + 1)) + 1UL : (unsigned long)value;

    char digits[24];   // least-significant digit first
    int d = 0;
    do { digits[d++] = (char)('0' + (int)(uv % 10)); uv /= 10; } while (uv);

    char rev[32];      // digits + commas, still reversed
    int t = 0;
    for (int i = 0; i < d; i++) {
        if (i && (i % 3) == 0) rev[t++] = ',';
        rev[t++] = digits[i];
    }

    char final[36];
    int f = 0;
    if (neg) final[f++] = '-';
    for (int i = t - 1; i >= 0; i--) final[f++] = rev[i];
    final[f] = '\0';

    size_t len = (size_t)f;
    if (n == 0) return len;
    size_t cpy = len < (n - 1) ? len : (n - 1);
    memcpy(out, final, cpy);
    out[cpy] = '\0';
    return len;
}
```

Create `firmware/components/fmt_num/CMakeLists.txt`:

```cmake
idf_component_register(SRCS "fmt_num.c" INCLUDE_DIRS "include")
```

- [ ] **Step 4: Run tests to verify they pass**

Run:
```bash
cmake --build firmware/host_test/build --target test_fmt_num
ctest --test-dir firmware/host_test/build -R test_fmt_num --output-on-failure
```
Expected: PASS — `test_fmt_num` passes all three test cases.

- [ ] **Step 5: Commit**

```bash
git add firmware/components/fmt_num firmware/host_test/test_fmt_num.c firmware/host_test/CMakeLists.txt
git commit -m "feat(fw): add fmt_num comma-grouping formatter with host tests"
```

---

## Task 2: Redesign the status screen (layout, palette, fonts, LED)

**Files:**
- Modify: `firmware/sdkconfig.defaults` (enable Montserrat 20 + 28)
- Modify: `firmware/main/CMakeLists.txt:4` (add `fmt_num` to `REQUIRES`)
- Modify: `firmware/main/status_display.c` (LVGL object graph in `lcd_init()`, rewrite `status_display_set()`, retune `led_set` callers)

**Interfaces:**
- Consumes: `fmt_thousands(long, char*, size_t)` from Task 1.
- Produces: no new public symbols — `status_display_init()` / `status_display_set()` unchanged externally.

- [ ] **Step 1: Enable the larger fonts**

Append to `firmware/sdkconfig.defaults`:

```
CONFIG_LV_FONT_MONTSERRAT_20=y
CONFIG_LV_FONT_MONTSERRAT_28=y
```

Regenerate config so the new symbols take effect (existing `sdkconfig` values win over defaults, so force a regen):

```bash
rm -f firmware/sdkconfig
idf.py -C firmware reconfigure
```

Verify the symbols are now set:
```bash
grep -E "CONFIG_LV_FONT_MONTSERRAT_(20|28)=y" firmware/sdkconfig
```
Expected: both lines present.

- [ ] **Step 2: Wire the `fmt_num` component into the main app**

Edit `firmware/main/CMakeLists.txt` line 4 — add `fmt_num` to `REQUIRES`:

```cmake
# firmware/main/CMakeLists.txt
idf_component_register(SRCS "app_main.c" "stepper.c" "usb_cdc.c" "controller.c" "status_display.c"
                       INCLUDE_DIRS "."
                       REQUIRES command_parser motion_math ramp fmt_num driver esp_lcd)
```

- [ ] **Step 3: Rewrite the LVGL object graph and render logic**

Replace `firmware/main/status_display.c` with the following. The hardware half of `lcd_init()` (SPI bus, panel, backlight, `lvgl_port_init`, `lvgl_port_add_disp`) is byte-for-byte the same as today; only the screen/object-creation block and `status_display_set()` change, plus the new include, static objects, and palette tables.

```c
// firmware/main/status_display.c
#include "status_display.h"
#include "pins.h"
#include "fmt_num.h"
#include "led_strip.h"
#include "esp_lcd_panel_io.h"
#include "esp_lcd_panel_ops.h"
#include "esp_lcd_panel_vendor.h"
#include "driver/spi_master.h"
#include "driver/gpio.h"
#include "driver/ledc.h"
#include "esp_lvgl_port.h"
#include "lvgl.h"
#include "esp_log.h"
#include <stdio.h>

static const char *TAG = "status_display";

#define LCD_BL_PIN        22
#define LCD_BL_DUTY_PCT   50          // backlight brightness (0-100)
#define LCD_BL_RES        LEDC_TIMER_8_BIT   // 0..255

#define COL_BG        0x0B0C0E
#define COL_VALUE     0xE8EAED
#define COL_CAPTION   0x8A9099
#define COL_DIVIDER   0x2A2D31

// Per-state palette, indexed by disp_state_t (DISCONNECTED, IDLE, MOVING, SETTLING).
static const uint32_t k_accent[]   = { 0x5A6B8C, 0x22C55E, 0xF5A623, 0x22D3EE };
static const char    *k_word[]     = { "OFFLINE", "READY", "ROTATING", "SETTLING" };
static const uint8_t  k_led[][3]   = { {10,14,24}, {0,34,12}, {40,22,0}, {0,28,28} };

static led_strip_handle_t s_led;
static lv_obj_t *s_bar, *s_dot, *s_div;
static lv_obj_t *s_l_state, *s_l_angle, *s_l_steps;

static void led_set(uint8_t r, uint8_t g, uint8_t b) {
    // Onboard LED reads RGB order; led_strip's WS2812 model emits GRB, so swap R<->G here.
    led_strip_set_pixel(s_led, 0, g, r, b);
    led_strip_refresh(s_led);
}

// A plain filled block with no border/padding/scroll — used for the accent bar and dot.
static lv_obj_t *make_block(lv_obj_t *parent, int w, int h, int radius) {
    lv_obj_t *o = lv_obj_create(parent);
    lv_obj_set_size(o, w, h);
    lv_obj_set_style_border_width(o, 0, 0);
    lv_obj_set_style_pad_all(o, 0, 0);
    lv_obj_set_style_radius(o, radius, 0);
    lv_obj_set_style_bg_opa(o, LV_OPA_COVER, 0);
    lv_obj_remove_flag(o, LV_OBJ_FLAG_SCROLLABLE);
    return o;
}

static lv_obj_t *make_label(lv_obj_t *parent, const lv_font_t *font, uint32_t color, int y) {
    lv_obj_t *l = lv_label_create(parent);
    lv_obj_set_style_text_font(l, font, 0);
    lv_obj_set_style_text_color(l, lv_color_hex(color), 0);
    lv_obj_align(l, LV_ALIGN_TOP_MID, 0, y);
    return l;
}

static void lcd_init(void) {
    spi_bus_config_t bus = { .mosi_io_num = 6, .sclk_io_num = 7, .miso_io_num = -1,
        .quadwp_io_num = -1, .quadhd_io_num = -1, .max_transfer_sz = 172*320*2 };
    ESP_ERROR_CHECK(spi_bus_initialize(SPI2_HOST, &bus, SPI_DMA_CH_AUTO));
    esp_lcd_panel_io_handle_t io;
    esp_lcd_panel_io_spi_config_t io_cfg = { .dc_gpio_num = 15, .cs_gpio_num = 14,
        .pclk_hz = 40*1000*1000, .lcd_cmd_bits = 8, .lcd_param_bits = 8,
        .spi_mode = 0, .trans_queue_depth = 10 };
    ESP_ERROR_CHECK(esp_lcd_new_panel_io_spi((esp_lcd_spi_bus_handle_t)SPI2_HOST, &io_cfg, &io));
    esp_lcd_panel_handle_t panel;
    esp_lcd_panel_dev_config_t pcfg = { .reset_gpio_num = 21, .rgb_ele_order = LCD_RGB_ELEMENT_ORDER_RGB, .bits_per_pixel = 16 };
    ESP_ERROR_CHECK(esp_lcd_new_panel_st7789(io, &pcfg, &panel));
    ESP_ERROR_CHECK(esp_lcd_panel_reset(panel));
    ESP_ERROR_CHECK(esp_lcd_panel_init(panel));
    esp_lcd_panel_invert_color(panel, true);
    esp_lcd_panel_set_gap(panel, 34, 0);   // 172-wide ST7789 offset; tune on bench
    esp_lcd_panel_disp_on_off(panel, true);

    // LCD backlight on GPIO22 via LEDC PWM at LCD_BL_DUTY_PCT brightness
    ledc_timer_config_t bl_timer = {
        .speed_mode = LEDC_LOW_SPEED_MODE,   // ESP32-C6 has only low-speed mode
        .duty_resolution = LCD_BL_RES,
        .timer_num = LEDC_TIMER_0,
        .freq_hz = 5000,
        .clk_cfg = LEDC_AUTO_CLK,
    };
    ESP_ERROR_CHECK(ledc_timer_config(&bl_timer));
    ledc_channel_config_t bl_ch = {
        .gpio_num = LCD_BL_PIN,
        .speed_mode = LEDC_LOW_SPEED_MODE,
        .channel = LEDC_CHANNEL_0,
        .timer_sel = LEDC_TIMER_0,
        .duty = ((1 << 8) - 1) * LCD_BL_DUTY_PCT / 100,   // 8-bit: 128 = 50%
        .hpoint = 0,
    };
    ESP_ERROR_CHECK(ledc_channel_config(&bl_ch));

    lvgl_port_cfg_t lp = ESP_LVGL_PORT_INIT_CONFIG();
    ESP_ERROR_CHECK(lvgl_port_init(&lp));
    lvgl_port_display_cfg_t dc = { .io_handle = io, .panel_handle = panel,
        .buffer_size = 172*40, .double_buffer = true, .hres = 172, .vres = 320,
        .rotation = { .swap_xy = false, .mirror_x = false, .mirror_y = false },
        .flags = { .swap_bytes = true } };   // RGB565 byte order for ST7789 (fixes colour fringe)
    lv_display_t *disp = lvgl_port_add_disp(&dc);
    lv_obj_t *scr = lv_display_get_screen_active(disp);   // LVGL 9.x

    // Dark canvas, no scrolling.
    lv_obj_set_style_bg_color(scr, lv_color_hex(COL_BG), 0);
    lv_obj_set_style_bg_opa(scr, LV_OPA_COVER, 0);
    lv_obj_remove_flag(scr, LV_OBJ_FLAG_SCROLLABLE);

    // Accent top bar (full width) + accent dot; colors set per-state in _set().
    s_bar = make_block(scr, 172, 6, 0);
    lv_obj_align(s_bar, LV_ALIGN_TOP_MID, 0, 0);
    s_dot = make_block(scr, 12, 12, LV_RADIUS_CIRCLE);
    lv_obj_align(s_dot, LV_ALIGN_TOP_MID, 0, 90);

    // Hero state word (accent color set per-state).
    s_l_state = make_label(scr, &lv_font_montserrat_28, COL_VALUE, 110);

    // Hairline divider.
    s_div = make_block(scr, 140, 1, 0);
    lv_obj_set_style_bg_color(s_div, lv_color_hex(COL_DIVIDER), 0);
    lv_obj_align(s_div, LV_ALIGN_TOP_MID, 0, 160);

    // Angle value + caption.
    s_l_angle = make_label(scr, &lv_font_montserrat_28, COL_VALUE, 185);
    lv_obj_t *cap_a = make_label(scr, &lv_font_montserrat_14, COL_CAPTION, 222);
    lv_label_set_text(cap_a, "ANGLE");

    // Steps value + caption.
    s_l_steps = make_label(scr, &lv_font_montserrat_20, COL_VALUE, 250);
    lv_obj_t *cap_s = make_label(scr, &lv_font_montserrat_14, COL_CAPTION, 280);
    lv_label_set_text(cap_s, "STEPS");
}

void status_display_init(void) {
    led_strip_config_t sc = { .strip_gpio_num = PIN_RGB_LED, .max_leds = 1,
                              .led_model = LED_MODEL_WS2812 };
    led_strip_rmt_config_t rc = { .resolution_hz = 10*1000*1000 };
    ESP_ERROR_CHECK(led_strip_new_rmt_device(&sc, &rc, &s_led));
    lcd_init();
    status_display_set(ST_DISCONNECTED, 0.0, 0);
}

void status_display_set(disp_state_t state, double angle_deg, long steps) {
    lv_color_t accent = lv_color_hex(k_accent[state]);
    led_set(k_led[state][0], k_led[state][1], k_led[state][2]);

    char a[32], s[32];
    snprintf(a, sizeof(a), "%.2f\xC2\xB0", angle_deg);   // UTF-8 degree sign (U+00B0)
    fmt_thousands(steps, s, sizeof(s));

    if (lvgl_port_lock(50)) {
        lv_obj_set_style_bg_color(s_bar, accent, 0);
        lv_obj_set_style_bg_color(s_dot, accent, 0);
        lv_obj_set_style_text_color(s_l_state, accent, 0);
        lv_label_set_text(s_l_state, k_word[state]);
        lv_label_set_text(s_l_angle, a);
        lv_label_set_text(s_l_steps, s);
        lvgl_port_unlock();
    } else {
        ESP_LOGW(TAG, "lvgl lock timeout");
    }
}
```

- [ ] **Step 4: Build gate (fonts compile in, flash fits)**

Run:
```bash
idf.py -C firmware build
```
Expected: build succeeds. If the linker errors with `undefined reference to lv_font_montserrat_20`/`_28`, the font regen in Step 1 did not apply — repeat the `rm -f firmware/sdkconfig && idf.py -C firmware reconfigure` and rebuild.

- [ ] **Step 5: Commit**

```bash
git add firmware/sdkconfig.defaults firmware/main/CMakeLists.txt firmware/main/status_display.c
git commit -m "feat(fw): redesign status LCD — minimalist dark theme, colored state word"
```

- [ ] **Step 6: On-bench visual sign-off (mandatory — cannot be automated)**

Flash and observe (per the spec's mandatory visual gate):
```bash
idf.py -C firmware flash monitor
```
Confirm, cycling states by issuing motion commands over USB (e.g. a `MOVEDEG`/`STEP` to trigger ROTATING → SETTLING → READY, plus the OFFLINE boot state):
1. Each state shows the correct accent color on the top bar, dot, and hero word.
2. The widest words ("ROTATING", "SETTLING") are not clipped at 172px, and the whole stack fits within 320px (no vertical clipping).
3. The `°` glyph renders in the angle line. **If it shows as a missing-glyph box**, change the `snprintf` format in `status_display_set()` from `"%.2f\xC2\xB0"` to `"%.2f deg"` and re-flash (fallback documented in the spec).
4. Steps read comma-grouped (e.g. `35,000`) and are legible.
5. The onboard LED hue matches the on-screen accent for each state.

Report the result; do not mark this plan complete until a human confirms the visual gate.

---

## Self-Review

**Spec coverage:**
- Layout A (accent bar + dot + hero + divider + angle/steps stack, centered on 172×320) → Task 2 Step 3. ✓
- Dark palette + per-state accent colors → Global Constraints + Task 2 tables. ✓
- Wording OFFLINE/READY/ROTATING/SETTLING → `k_word[]`, Task 2. ✓
- LED re-tuned to matching hues → `k_led[]` + `led_set` in `status_display_set()`. ✓
- Fonts Montserrat 20 + 28 enabled → Task 2 Step 1. ✓
- No API change; `disp_state_t`, `status_display_set` signature, controller untouched → Global Constraints; only `status_display.c`/CMake/sdkconfig touched. ✓
- `°` glyph with documented fallback → Task 2 Step 3 code + Step 6 item 3. ✓
- Comma-grouped steps → Task 1 (tested) + used in Task 2. ✓
- Lock guard + LED outside lock → preserved in `status_display_set()`. ✓
- Build gate + mandatory bench visual sign-off → Task 2 Steps 4 and 6. ✓

**Placeholder scan:** No TBD/TODO; every code step shows complete code; no "handle edge cases" hand-waving (edge cases enumerated in Task 1 tests). ✓

**Type consistency:** `fmt_thousands(long, char*, size_t) -> size_t` is declared in the Task 1 header, tested in Task 1, and called identically in Task 2. State-indexed tables `k_accent`/`k_word`/`k_led` share the `disp_state_t` ordering used by `state` in `status_display_set()`. ✓

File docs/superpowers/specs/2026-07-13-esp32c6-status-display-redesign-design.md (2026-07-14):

# ESP32-C6 Status Display Redesign

**Date:** 2026-07-13
**Component:** `firmware/main/status_display.c` (+ `.h`), `firmware/sdkconfig.defaults`
**Status:** Design approved, pending spec review

## Goal

Redesign the on-device LCD status screen so an observer can tell, at a glance and
across the room, what the scanner is currently doing. Replace the current three
plain top-left text labels with a minimalist dark-theme layout built around a
large, color-coded state word. Re-tune the onboard RGB LED to the same palette so
the two indicators agree.

## Hardware / platform constraints (fixed)

- Display: ST7789 LCD, **172 wide × 320 tall**, portrait. Color inversion on,
  RGB565 with byte swap (already configured in `lcd_init()`).
- Onboard WS2812 RGB LED (single pixel), driven via `led_set(r,g,b)` which already
  swaps R<->G for the board's GRB ordering.
- LVGL 9.x via `esp_lvgl_port`, configured through Kconfig/`sdkconfig` (no manual
  `lv_conf.h`). Default font is Montserrat 14; larger sizes are **not** compiled in.
- Rendering must hold the LVGL lock (`lvgl_port_lock`/`_unlock`), as today.

## Scope

**In scope**

- New screen layout and styling in `status_display.c`.
- New state wording and dark-theme color palette.
- Enable the larger Montserrat fonts needed for the hero/value text.
- Re-tune LED colors to match the new per-state palette.

**Out of scope (unchanged)**

- `status_display_set(disp_state_t, double angle_deg, long steps)` signature and
  its call sites in `controller.c` stay exactly as they are.
- No new data surfaced (speed/accel/settle/res are NOT added to the display).
- `disp_state_t` enum values stay the same (`ST_DISCONNECTED`, `ST_IDLE`,
  `ST_MOVING`, `ST_SETTLING`); only their *displayed words and colors* change.
- No change to when states are set or to connection detection.

## Layout (Approach A — accent top-bar + centered stack)

Background near-black `#0B0C0E`. One accent color per state; all other text is
white/grey. The content group is centered vertically in the 320px canvas.

```
┌────────────────┐   172 x 320
│▓▓▓▓▓▓▓▓▓▓▓▓▓▓▓▓│  ← 6px full-width accent bar (state color), pinned to top edge
│                │
│       ●        │  ← 12px round dot, accent color
│                │
│   ROTATING     │  ← Montserrat 28, accent color   (HERO)
│                │
│ ────────────── │  ← 1px hairline divider, #2A2D31
│                │
│    142.50°     │  ← Montserrat 28, near-white #E8EAED
│     ANGLE      │  ← Montserrat 14, grey #8A9099   (caption)
│                │
│     35,000     │  ← Montserrat 20, near-white #E8EAED
│     STEPS      │  ← Montserrat 14, grey #8A9099   (caption)
│                │
└────────────────┘
```

Alignment: everything horizontally centered on the 172px width. The dot → hero →
divider → angle block → steps block form one vertical stack centered around the
screen middle.

### Elements and LVGL objects

Persistent objects created once in `lcd_init()` (extending the current
`s_l_state/s_l_angle/s_l_steps` set), stored as file-static:

- `s_bar`   — top accent bar: `lv_obj_t` rectangle, 172×6, aligned `TOP_MID`.
- `s_dot`   — accent dot: small rounded `lv_obj_t`, 12×12, radius = full.
- `s_l_state` — hero label, Montserrat 28.
- `s_div`   — hairline: `lv_obj_t` 140×1, color `#2A2D31`.
- `s_l_angle` — angle value, Montserrat 28.
- `s_cap_angle` — static caption "ANGLE", Montserrat 14, grey (set once).
- `s_l_steps` — steps value, Montserrat 20.
- `s_cap_steps` — static caption "STEPS", Montserrat 14, grey (set once).

The screen background is set to `#0B0C0E` once at init.

## State palette and wording

`status_display_set()` maps state → {word, accent color}. LED gets the same accent
(scaled down to the LED's dim brightness range as today).

| Enum | Displayed word | Accent (hex) | LED (r,g,b, dim) | Meaning |
|---|---|---|---|---|
| ST_DISCONNECTED | OFFLINE | #5A6B8C | (10, 14, 24) | no host link |
| ST_IDLE | READY | #22C55E | (0, 34, 12) | waiting for command  |
| ST_MOVING | ROTATING | #F5A623 | (40, 22, 0) | turntable in motion  |
| ST_SETTLING | SETTLING | #22D3EE | (0, 28, 28) | holding to stabilize |

LED values keep today's low brightness (the panel LED is bright); exact triplets
above are the intent and may be nudged on the bench. The mapping (blue/green/
amber/cyan) matches the current LED semantics, so behavior is consistent, just
recolored to align with the screen.

On each `status_display_set()` call: set the accent color on `s_bar`, `s_dot`, and
`s_l_state`; set hero text to the word; update angle and steps text; set LED.

### Text formatting

- Angle: `"%.2f°"` — matches current 2-decimal precision. The `°` glyph is ASCII
  0xB0; confirm it renders in the compiled Montserrat 28 set, else fall back to
  `" deg"` suffix or a drawn ring. (Verify on bench; documented as a build check.)
- Steps: thousands-grouped for readability (e.g. `35,000`). A small helper formats
  a `long` with comma separators into the existing stack buffer.

## Font configuration

Add to `firmware/sdkconfig.defaults`:

```
CONFIG_LV_FONT_MONTSERRAT_20=y
CONFIG_LV_FONT_MONTSERRAT_28=y
```

Montserrat 14 is already enabled and remains the default. Two extra glyph tables
add modest flash; acceptable. Reference the fonts in C as `&lv_font_montserrat_20`
and `&lv_font_montserrat_28`.

## Data flow

Unchanged from today:

```
controller.c do_move()/init  ──►  status_display_set(state, angle, steps)
                                        │
                                        ├─► LVGL: lock → set accent+text on
                                        │         bar/dot/hero/angle/steps → unlock
                                        └─► led_set(accent-dim)
```

`status_display_init()` still calls `status_display_set(ST_DISCONNECTED, 0.0, 0)`
at the end, so the redesigned OFFLINE screen is the boot state.

## Error handling

- Keep the existing `lvgl_port_lock(50)` guard; on timeout, log a warning and skip
  the frame (as today). The LED update stays outside the lock so status color
  still updates even if LVGL is briefly busy.
- All label/object creation is checked implicitly by LVGL; init runs once at boot.

## Testing

This is embedded UI; verification is primarily on-device visual plus a build gate.

1. **Build gate:** `idf.py build` for `esp32c6` succeeds with the new fonts and
   sdkconfig entries (confirms fonts compile in and flash fits).
2. **Bench visual check (mandatory sign-off):** flash and confirm each of the four
   states renders correctly — accent bar/dot/hero color, centered layout within
   172×320 (no clipping of the widest word "SETTLING"/"ROTATING"), angle & steps
   legibility, `°` glyph renders (or fallback applied), LED hue matches screen.
   Cycle states by issuing motion commands over USB and observing MOVING→SETTLING→
   READY, plus the OFFLINE boot state.
3. No host unit test — the drawing code is LVGL-call-only with no separable logic
   except the comma-grouping helper, which can be exercised by the existing
   `firmware/host_test` harness if a quick assert is cheap to add.

## Open verification items (resolve during implementation)

- Confirm `°` renders in Montserrat 28; else apply `" deg"` fallback.
- Confirm total layout height fits 320px with the chosen paddings (angle block +
  steps block + hero + bar); adjust vertical gaps if tight.
- Nudge LED brightness triplets on the bench for even perceived brightness across
  hues.

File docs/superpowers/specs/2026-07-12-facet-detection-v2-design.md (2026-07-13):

# Facet Detection v2 — segment-and-cluster on raw support data

**Date:** 2026-07-12
**Status:** Design approved (conversation), supersedes the *detection front-end* of
`2026-07-11-faceted-gem-reconstruction-design.md`. The exact-refit and
half-space-assembly back-end of that design is retained unchanged.

---

## 1. Why v1 detection failed (root cause, verified on gem04)

v1 seeded facet candidates by Gauss-sphere clustering of the **soft-hull**
mesh's face normals. On synthetic ground truth this worked (the hull of an
already-perfect polyhedron keeps sharp faces). On the real gem04 it failed
completely — visual comparison shows the output does not represent the actual
facets:

- The soft hull is smooth **by construction**; its normals are a coarse angular
  sampling of a rounded surface, not real facets. Evidence: the girdle ring
  collapsed to **1** normal cluster (53 seeds total, none girdle-vertical).
- Scans are captured **culet-up** (table down). v1 unconditionally capped both
  z-extremes with horizontal planes → a flat lid over the culet *point*.
- Net result: a crude convex envelope (+5–6 % oversize), wrong facet layout,
  blunted apex. Numbers (watertight, 32.8 µm median fit) looked plausible while
  the geometry was wrong — **numerical validation without visual verification
  against the real stone was the process failure.**

Root causes: (A) culet cap — a bug; (B) soft-hull seed — architectural: it
destroys the facet information before detection starts.

## 2. Spike result that validates v2 (gem04, real data)

Segmenting the **raw** support function `H(z)` per view into affine pieces
(after a k≈9 median along z) recovers the step-cut structure directly:

- ~17–20 affine segments per principal azimuth, typical **rms ≈ 5 µm**
  (v1: 32.8 µm median / 165 µm max).
- Clean tilt ladder from table to culet: ≈27° → 39° → 45° → 51° → 60°
  (pavilion steps), plus crown ≈ −55° tiers below the girdle — unmistakably the
  real step cut.
- Girdle cross-section (strip slices, sharp) shows ~4 principal sides at
  ≈74°/162°/252°/342°.
- Dropping the culet cap: assembly stays watertight and converges to a single
  apex vertex; extents move toward gem.stl (8.88 → 8.61 mm X).

The facet information is present and sharp in the raw data; only the soft-hull
front-end was discarding it.

## 3. Scope

- Cuts: **step cuts and brilliant cuts** (general convex faceted stones); no
  cut template, unsupervised.
- Orientation: capture protocol is **culet-up (table down)**; v2 detects
  orientation from the silhouette width profile rather than assuming it.
- Validation: **gem04 (real step cut) is the acceptance bar**, including a
  visual facet-layout comparison. Brilliant validation deferred until a real
  brilliant scan exists. Synthetic toy-gem e2e remains as a regression test —
  explicitly necessary-not-sufficient.

## 4. Pipeline (replaces v1 stages 2–3; everything else retained)

`method="facet"` in `FacetReconstructor.reconstruct`:

1. **Support maps** — existing `support_maps(dataset, params)`. Unchanged.
2. **Per-view affine segmentation** (new, productionized spike):
   for each view `i`, estimate the local slope `dH/dz` by sliding-window
   Theil–Sen (window `facet_seg_median_rows`, default 17 — rank-robust, no
   pre-filtering: a blanket median staircases sloped columns), split into
   segments at run-maxima of the two-sided slope jump above `facet_slope_jump`
   (default 0.12), trim the k-row transition zone, and fit each segment with
   the frozen robust `fit_affine_support`, with minimum segment span
   `facet_min_seg_mm` (default 0.25 mm) and ≥ `facet_min_inliers` rows. Per
   segment record `(i, z_lo, z_hi, α, β, rms)`. (Revised from the original
   slope-derivative criterion, which was numerically verified noise-fragile.)
3. **Facet azimuths from cross-slice polygon edges** (new — AMENDED 2026-07-12,
   user-approved): the strip cross-section polygons' edges ARE the facet traces.
   Cluster all slice-polygon edges (outward-normal azimuth, length-weighted)
   across z into azimuth families; edges shorter than `facet_min_edge_mm`
   (default 0.35 mm, above the carve quantum R·Δθ) are noise from view
   quantization at polygon corners and are skipped. Each family = one facet
   azimuth θ\* (length-weighted circular mean; 0.2° accuracy on the toy gate).
   *The spec's original cross-view chain clustering was pre-verified to FAIL
   the toy gate (2.5° median): chains conflate facet traces with polygon-corner
   (arris) traces — crown chains center on vertex directions. `cluster_segments`
   remains in the module (tested) but is not used by the facet path.*
4. **Per-azimuth tier segmentation + exact refit** — at each family's nearest
   view, `segment_support` splits the raw `H(z)` into affine tiers
   (`facet_seg_median_rows` default 17: at 1-px support quantization the
   Theil–Sen slope noise is ≈ pixel/(2k·Δz); k=8 keeps it under half the
   0.12 jump threshold — verified on the toy gate and gem04); each tier is
   refit by the frozen `fit_affine_support` → `plane_from_affine` → exact
   plane `(a,b,c,d)`. Girdle facets are the α≈0 tiers; no special case.
   Note: tiers narrower than ~(2k+8) rows are absorbed into neighbours — on
   gem04 the absorbed spans still fit ONE plane at ≤8 µm rms (they were
   over-segmentation in the spike, not real distinct tiers).
5. **Table/culet, orientation-aware** (new):
   - Orientation from the silhouette width profile: the z-extreme whose
     silhouette is wide + flat (width > `facet_table_width_frac` (default 0.3)
     of the girdle width over a plateau) is the **table** → emit horizontal
     plane there. The converging extreme is the **culet** → **no cap**; the
     pavilion planes close the apex.
   - If neither extreme qualifies as a table (unusual), emit no extremal
     planes; if assembly then fails to bound, the existing fallback fires.
6. **Assembly** — existing `_merge_planes` (scale-relative) →
   `planes_to_polytope` → watertight mesh, `metadata["facets"]` =
   {planes, rms, vertices, edges}. Unchanged.

**Removed from the facet path:** SoftHullReconstructor seeding, `seed_facets`
usage, `annotate_seed_z_extent`. (`seed_facets` stays in the module — harmless,
tested — but the facet path no longer calls it. soft_hull remains a standalone
method and the fallback target.)

## 5. Params (replace v1 facet knobs where noted)

```
facet_seg_median_rows: int = 17     # Theil-Sen slope window (rows)
facet_slope_jump: float = 0.12      # min two-sided slope jump between tiers
facet_min_seg_mm: float = 0.25      # min tier z-span
facet_min_edge_mm: float = 0.35     # min slice-polygon edge (carve-quantum filter)
facet_table_width_frac: float = 0.3 # table plateau width vs girdle width
facet_min_inliers: int = 8          # min rows per tier / refit inliers
# retained: facet_merge_deg, facet_fallback
# dropped: facet_view_search, facet_axial_cos (v1-seed), facet_min_views,
#          facet_slope_tol (chain clustering, superseded by edge azimuths)
```

## 6. Acceptance criteria (gates, in order)

1. **Toy-gem synthetic e2e** still passes (median normal error <1°, watertight,
   volume <5%) — regression only.
2. **gem04 quantitative**: per-facet refit rms at spike levels (median ≤15 µm);
   tilt tiers match the spike ladder (≈27/39/45/51/60° pavilion, ≈−55° crown);
   extents within ~50 µm of gem.stl per axis; watertight; single-vertex apex at
   the culet end (no horizontal cap plane with normal toward the culet).
3. **gem04 visual (the gate v1 skipped)**: side-by-side render of
   `gem_facet.stl` vs `gem.stl`; the facet layout (tier boundaries, side
   azimuths) must visibly match the real stone. Deliver the rendered image for
   the user's judgement — user sign-off required before merge.

## 7. Risks

| Risk | Mitigation |
|---|---|
| Cross-view clustering splits/merges facets | gem04 segments are extremely clean (5 µm); spike output is the debugging reference; `facet_min_views`/`facet_slope_tol` tunable |
| Segment breakpoints drift with noise | median-along-z pre-filter (rank-based, facet-preserving — same property as the shipped de-terracing) |
| Brilliant cuts untested | explicitly deferred; design has no step-cut-specific assumption (clustering is generic) |
| holder_mask_rows still not in manifest | unchanged known product gap (F1); validation script supplies 705 |

## 8. Non-goals

- No brilliant-cut validation in this iteration (deferred; no real scan).
- No multi-axis capture, no concave facets, no cut identification.
- No change to strip/soft_hull methods, GUI wiring, or fallback semantics.

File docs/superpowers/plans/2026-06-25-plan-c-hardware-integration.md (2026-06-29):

# Plan C — Hardware Integration (PC App) Implementation Plan

> **For agentic workers:** REQUIRED SUB-SKILL: Use superpowers:subagent-driven-development (recommended) or superpowers:executing-plans to implement this plan task-by-task. Steps use checkbox (`- [ ]`) syntax for tracking.

**Goal:** The Python PC application that ties the project together — a camera abstraction, a motion client that speaks the Plan B firmware protocol, a step-and-settle `ScanController` with a pre-scan FoV/eccentricity check, calibration routines, and a CLI with an Open3D 3D viewer — producing a scan dataset that Plan A reconstructs into a mesh.

**Architecture:** Extends the existing `gemscanner` package (Plan A). Hardware is hidden behind small interfaces so the orchestration is host-testable without a camera or board: a `CameraBackend` (mock / OpenCV / Baumer) and a serial `Transport` (real pyserial / in-process `FakeFirmware` that emulates the Plan B controller). The `ScanController` drives `stage.move_deg → wait READY → camera.grab → save`, writing a Plan A `ScanManifest`; reconstruction reuses `reconstruction.pipeline.reconstruct_dataset`. Pure logic + fakes are unit-tested; real serial, real cameras, and the Open3D window are bench-verified.

**Tech Stack:** Python 3.11+, NumPy, OpenCV, trimesh (Plan A), **pyserial**, **open3d**, **pyyaml** (new). Baumer **neoAPI** is an optional, separately-installed SDK (not on PyPI), imported lazily.

## Global Constraints

- Python **3.11+**, Windows. Build on the existing `gemscanner` package; reuse `storage.ScanManifest`/`ScanDataset`, `vision.extract_silhouette`, `reconstruction.pipeline.reconstruct_dataset`, `storage.mesh_io.export_mesh` — do **not** reimplement them.
- New runtime deps: `pyserial`, `open3d`, `pyyaml`. `neoapi` is **optional** and separately installed (Baumer); `BaumerCamera` imports it lazily so `import gemscanner` works without it.
- The venv is at `.venv`; run everything via `.venv/Scripts/python.exe -m ...` (Windows, Git Bash).
- The motion client MUST speak the **Plan B firmware protocol exactly** (see `firmware/README.md`): line commands `STEP/MOVEDEG/SETV/SETACC/SETSETTLE/SETRES/HOME/STATUS`; a move replies `OK` then `READY` after move+settle; errors are `ERR nores|badarg|unknown`; `STATUS` returns `STATUS angle=… steps=… state=idle v=… a=… settle=… res=…`; **steps-per-360° is set at runtime via `SETRES`** and `MOVEDEG` returns `ERR nores` until it is. The in-process `FakeFirmware` test double emulates this and is the contract.
- **Frames are registered to the calibrated rotation axis and never re-centered** (Plan A constraint), so the manifest carries `axis_column`/`axis_tilt_rad` and `ScanController` does no per-frame cropping.
- Hardware-touching code (real `SerialTransport`, `OpenCvCamera.grab`, `BaumerCamera`, the Open3D window) is **bench-verified**; everything else is host-tested with pytest. Tasks 10–12 require hardware and are marked **BENCH**.

---

### Task 1: Dependencies + configuration

**Files:**
- Modify: `pyproject.toml` (add deps + `gemscanner` console entry point)
- Create: `gemscanner/config.py`
- Test: `tests/test_config.py`

**Interfaces:**
- Consumes: `pyyaml`.
- Produces: `ScannerConfig` dataclass (`camera_backend: str`, `camera: dict`, `serial_port: str`, `serial_baud: int = 115200`, `scan: dict`, `calibration_path: str`) with `@classmethod load(path)` and `save(path)` (YAML); `default_config() -> ScannerConfig`.

- [ ] **Step 1: Install new deps and write the failing test**

```bash
.venv/Scripts/python.exe -m pip install pyserial open3d pyyaml
```

```python
# tests/test_config.py
from gemscanner.config import ScannerConfig, default_config

def test_roundtrip(tmp_path):
    c = default_config()
    c.serial_port = "COM7"
    c.scan["n_views"] = 360
    p = tmp_path / "cfg.yaml"
    c.save(p)
    loaded = ScannerConfig.load(p)
    assert loaded.serial_port == "COM7"
    assert loaded.scan["n_views"] == 360
    assert loaded.camera_backend == "mock"

def test_defaults():
    c = default_config()
    assert c.serial_baud == 115200
    assert c.camera_backend in ("mock", "opencv", "baumer")
```

- [ ] **Step 2: Run test to verify it fails**

Run: `.venv/Scripts/python.exe -m pytest tests/test_config.py -v`
Expected: FAIL (`ModuleNotFoundError: gemscanner.config`).

- [ ] **Step 3: Implement**

```python
# gemscanner/config.py
from dataclasses import dataclass, field, asdict
import yaml

@dataclass
class ScannerConfig:
    camera_backend: str = "mock"
    camera: dict = field(default_factory=dict)
    serial_port: str = "COM3"
    serial_baud: int = 115200
    scan: dict = field(default_factory=lambda: {"n_views": 180, "settle_ms": 150})
    calibration_path: str = "calibration.json"

    def save(self, path):
        with open(path, "w", encoding="utf-8") as f:
            yaml.safe_dump(asdict(self), f, sort_keys=False)

    @classmethod
    def load(cls, path):
        with open(path, encoding="utf-8") as f:
            data = yaml.safe_load(f)
        return cls(**data)

def default_config():
    return ScannerConfig()
```

Add to `pyproject.toml` `[project].dependencies`: `"pyserial"`, `"open3d"`, `"pyyaml"`. Add:
```toml
[project.scripts]
gemscanner = "gemscanner.cli:main"
```

- [ ] **Step 4: Run test to verify it passes**

Run: `.venv/Scripts/python.exe -m pip install -e . && .venv/Scripts/python.exe -m pytest tests/test_config.py -v`
Expected: PASS.

- [ ] **Step 5: Commit**

```bash
git add pyproject.toml gemscanner/config.py tests/test_config.py
git commit -m "feat: scanner config (YAML) and Plan C dependencies"
```

---

### Task 2: Camera backend interface + MockCamera

**Files:**
- Create: `gemscanner/camera/__init__.py`
- Create: `gemscanner/camera/base.py`
- Create: `gemscanner/camera/mock.py`
- Test: `tests/camera/test_mock.py`

**Interfaces:**
- Consumes: nothing (numpy).
- Produces:
  - `CameraBackend` (ABC): `open()`, `close()`, `set_exposure(us: float)`, `grab() -> np.ndarray` (grayscale `uint8`). Context-manager support via `__enter__/__exit__`.
  - `MockCamera(frames=None, frame_provider=None)`: returns successive `frames`, or calls `frame_provider()` per `grab()`. Host-testable stand-in.

- [ ] **Step 1: Write the failing test**

```python
# tests/camera/test_mock.py
import numpy as np
from gemscanner.camera.mock import MockCamera

def test_returns_frames_in_order():
    f0 = np.zeros((4, 4), np.uint8)
    f1 = np.ones((4, 4), np.uint8)
    cam = MockCamera(frames=[f0, f1])
    cam.open()
    assert np.array_equal(cam.grab(), f0)
    assert np.array_equal(cam.grab(), f1)
    cam.close()

def test_frame_provider_called():
    calls = {"n": 0}
    def provider():
        calls["n"] += 1
        return np.full((2, 2), calls["n"], np.uint8)
    cam = MockCamera(frame_provider=provider)
    assert cam.grab()[0, 0] == 1
    assert cam.grab()[0, 0] == 2

def test_context_manager():
    with MockCamera(frames=[np.zeros((2, 2), np.uint8)]) as cam:
        assert cam.grab().shape == (2, 2)
```

- [ ] **Step 2: Run test to verify it fails**

Run: `.venv/Scripts/python.exe -m pytest tests/camera/test_mock.py -v`
Expected: FAIL (`ModuleNotFoundError`).

- [ ] **Step 3: Implement**

```python
# gemscanner/camera/__init__.py
```

```python
# gemscanner/camera/base.py
from abc import ABC, abstractmethod

class CameraBackend(ABC):
    @abstractmethod
    def open(self): ...
    @abstractmethod
    def close(self): ...
    @abstractmethod
    def grab(self): ...

    def set_exposure(self, us):
        pass

    def __enter__(self):
        self.open()
        return self

    def __exit__(self, *exc):
        self.close()
        return False
```

```python
# gemscanner/camera/mock.py
from gemscanner.camera.base import CameraBackend

class MockCamera(CameraBackend):
    def __init__(self, frames=None, frame_provider=None):
        self._frames = list(frames) if frames is not None else None
        self._provider = frame_provider
        self._i = 0

    def open(self):
        self._i = 0

    def close(self):
        pass

    def grab(self):
        if self._provider is not None:
            return self._provider()
        frame = self._frames[self._i]
        self._i = min(self._i + 1, len(self._frames) - 1)
        return frame
```

- [ ] **Step 4: Run test to verify it passes**

Run: `.venv/Scripts/python.exe -m pytest tests/camera/test_mock.py -v`
Expected: PASS.

- [ ] **Step 5: Commit**

```bash
git add gemscanner/camera/__init__.py gemscanner/camera/base.py gemscanner/camera/mock.py tests/camera/test_mock.py
git commit -m "feat: camera backend interface and MockCamera"
```

---

### Task 3: Serial transport + FakeFirmware test double

**Files:**
- Create: `gemscanner/motion/__init__.py`
- Create: `gemscanner/motion/transport.py`
- Create: `gemscanner/motion/fake_firmware.py`
- Test: `tests/motion/test_fake_firmware.py`

**Interfaces:**
- Consumes: `pyserial` (only in `SerialTransport`).
- Produces:
  - `Transport` (Protocol/ABC): `write_line(s: str)`, `read_line(timeout: float | None = None) -> str | None`, `close()`.
  - `SerialTransport(port, baud=115200, timeout=2.0)` — pyserial-backed (bench).
  - `FakeFirmware()` — in-process `Transport` that emulates the Plan B controller: tracks `pos_steps`, `steps_per_rev`, `v/a/settle`; on a written command queues the exact reply lines (`OK` then `READY` for moves; `ERR nores` for `MOVEDEG` before `SETRES`; `STATUS …`; `ERR badarg`/`ERR unknown`). `read_line` pops queued replies.

- [ ] **Step 1: Write the failing test**

```python
# tests/motion/test_fake_firmware.py
from gemscanner.motion.fake_firmware import FakeFirmware

def drain(fw):
    out = []
    while True:
        line = fw.read_line(timeout=0)
        if line is None:
            break
        out.append(line)
    return out

def test_step_replies_ok_then_ready():
    fw = FakeFirmware()
    fw.write_line("STEP 100")
    assert drain(fw) == ["OK", "READY"]

def test_movedeg_blocked_until_setres():
    fw = FakeFirmware()
    fw.write_line("MOVEDEG 90")
    assert drain(fw) == ["ERR nores"]
    fw.write_line("SETRES 20000")
    assert drain(fw) == ["OK"]
    fw.write_line("MOVEDEG 90")
    assert drain(fw) == ["OK", "READY"]

def test_status_tracks_position_and_res():
    fw = FakeFirmware()
    fw.write_line("SETRES 20000"); drain(fw)
    fw.write_line("STEP 5000"); drain(fw)
    fw.write_line("STATUS")
    line = drain(fw)[0]
    assert line.startswith("STATUS ")
    assert "steps=5000" in line
    assert "res=20000" in line
    assert "angle=90.000" in line   # 5000/20000*360

def test_unknown_and_badarg():
    fw = FakeFirmware()
    fw.write_line("WIGGLE"); assert drain(fw) == ["ERR unknown"]
    fw.write_line("SETV abc"); assert drain(fw) == ["ERR badarg"]
```

- [ ] **Step 2: Run test to verify it fails**

Run: `.venv/Scripts/python.exe -m pytest tests/motion/test_fake_firmware.py -v`
Expected: FAIL (`ModuleNotFoundError`).

- [ ] **Step 3: Implement**

```python
# gemscanner/motion/__init__.py
```

```python
# gemscanner/motion/transport.py
class SerialTransport:
    """pyserial-backed transport (bench)."""
    def __init__(self, port, baud=115200, timeout=2.0):
        import serial
        self._ser = serial.Serial(port, baud, timeout=timeout)

    def write_line(self, s):
        self._ser.write((s + "\n").encode("ascii"))

    def read_line(self, timeout=None):
        if timeout is not None:
            self._ser.timeout = timeout
        raw = self._ser.readline()
        if not raw:
            return None
        return raw.decode("ascii", "replace").strip()

    def close(self):
        self._ser.close()
```

```python
# gemscanner/motion/fake_firmware.py
from collections import deque

class FakeFirmware:
    """In-process Transport emulating the Plan B controller protocol."""
    def __init__(self):
        self._out = deque()
        self.pos_steps = 0
        self.steps_per_rev = 0
        self.v, self.a, self.settle = 4000, 20000, 150

    def write_line(self, s):
        parts = s.strip().split()
        if not parts:
            self._out.append("ERR unknown"); return
        verb, args = parts[0].upper(), parts[1:]

        def as_int():
            return int(args[0])

        try:
            if verb == "STEP":
                self.pos_steps += as_int(); self._out += ["OK", "READY"]
            elif verb == "MOVEDEG":
                deg = float(args[0])
                if self.steps_per_rev <= 0:
                    self._out.append("ERR nores")
                else:
                    self.pos_steps += round(deg / 360.0 * self.steps_per_rev)
                    self._out += ["OK", "READY"]
            elif verb == "SETRES":
                n = as_int()
                if n > 0:
                    self.steps_per_rev = n; self._out.append("OK")
                else:
                    self._out.append("ERR badarg")
            elif verb == "SETV":
                self.v = as_int(); self._out.append("OK")
            elif verb == "SETACC":
                self.a = as_int(); self._out.append("OK")
            elif verb == "SETSETTLE":
                self.settle = as_int(); self._out.append("OK")
            elif verb == "HOME":
                self.pos_steps = 0; self._out += ["OK", "READY"]
            elif verb == "STATUS":
                angle = (self.pos_steps / self.steps_per_rev * 360.0) % 360.0 if self.steps_per_rev else 0.0
                self._out.append(
                    f"STATUS angle={angle:.3f} steps={self.pos_steps} state=idle "
                    f"v={self.v} a={self.a} settle={self.settle} res={self.steps_per_rev}")
            else:
                self._out.append("ERR unknown")
        except (ValueError, IndexError):
            self._out.append("ERR badarg")

    def read_line(self, timeout=None):
        return self._out.popleft() if self._out else None

    def close(self):
        pass
```

- [ ] **Step 4: Run test to verify it passes**

Run: `.venv/Scripts/python.exe -m pytest tests/motion/test_fake_firmware.py -v`
Expected: PASS.

- [ ] **Step 5: Commit**

```bash
git add gemscanner/motion/__init__.py gemscanner/motion/transport.py gemscanner/motion/fake_firmware.py tests/motion/test_fake_firmware.py
git commit -m "feat: serial transport and FakeFirmware protocol double"
```

---

### Task 4: RotaryStage client

**Files:**
- Create: `gemscanner/motion/stage.py`
- Test: `tests/motion/test_stage.py`

**Interfaces:**
- Consumes: `motion.transport`/`fake_firmware` (any `Transport`).
- Produces:
  - `StageError(Exception)`.
  - `RotaryStage(transport, reply_timeout=2.0, move_timeout=60.0)` with:
    `set_resolution(steps_per_rev)`, `set_speed(v)`, `set_accel(a)`, `set_settle(ms)`,
    `step(microsteps)`, `move_deg(deg)`, `home()`, `status() -> dict`.
    Move methods send the command, require an `OK`, then block for `READY` (up to `move_timeout`). Any `ERR …` raises `StageError`. `status()` parses the `STATUS` line into a dict of typed fields.

- [ ] **Step 1: Write the failing test**

```python
# tests/motion/test_stage.py
import pytest
from gemscanner.motion.fake_firmware import FakeFirmware
from gemscanner.motion.stage import RotaryStage, StageError

def test_step_and_status_roundtrip():
    stage = RotaryStage(FakeFirmware())
    stage.set_resolution(20000)
    stage.step(5000)
    st = stage.status()
    assert st["steps"] == 5000
    assert st["res"] == 20000
    assert abs(st["angle"] - 90.0) < 1e-6

def test_move_deg_before_setres_raises():
    stage = RotaryStage(FakeFirmware())
    with pytest.raises(StageError):
        stage.move_deg(90)

def test_move_deg_after_setres():
    stage = RotaryStage(FakeFirmware())
    stage.set_resolution(36000)
    stage.move_deg(45)
    assert stage.status()["steps"] == 4500

def test_home_zeroes():
    stage = RotaryStage(FakeFirmware())
    stage.set_resolution(20000); stage.step(1234); stage.home()
    assert stage.status()["steps"] == 0
```

- [ ] **Step 2: Run test to verify it fails**

Run: `.venv/Scripts/python.exe -m pytest tests/motion/test_stage.py -v`
Expected: FAIL (`ModuleNotFoundError`).

- [ ] **Step 3: Implement**

```python
# gemscanner/motion/stage.py
class StageError(Exception):
    pass

class RotaryStage:
    def __init__(self, transport, reply_timeout=2.0, move_timeout=60.0):
        self._t = transport
        self._reply_timeout = reply_timeout
        self._move_timeout = move_timeout

    def _send_ok(self, line, timeout):
        self._t.write_line(line)
        reply = self._t.read_line(timeout=timeout)
        if reply is None:
            raise StageError(f"timeout waiting for reply to {line!r}")
        if reply.startswith("ERR"):
            raise StageError(f"{line!r} -> {reply}")
        if reply != "OK":
            raise StageError(f"{line!r} -> unexpected {reply!r}")

    def _move(self, line):
        self._send_ok(line, self._reply_timeout)
        ready = self._t.read_line(timeout=self._move_timeout)
        if ready != "READY":
            raise StageError(f"{line!r} -> expected READY, got {ready!r}")

    def set_resolution(self, steps_per_rev):
        self._send_ok(f"SETRES {int(steps_per_rev)}", self._reply_timeout)

    def set_speed(self, v):
        self._send_ok(f"SETV {int(v)}", self._reply_timeout)

    def set_accel(self, a):
        self._send_ok(f"SETACC {int(a)}", self._reply_timeout)

    def set_settle(self, ms):
        self._send_ok(f"SETSETTLE {int(ms)}", self._reply_timeout)

    def step(self, microsteps):
        self._move(f"STEP {int(microsteps)}")

    def move_deg(self, deg):
        self._move(f"MOVEDEG {deg}")

    def home(self):
        self._move("HOME")

    def status(self):
        self._t.write_line("STATUS")
        line = self._t.read_line(timeout=self._reply_timeout)
        if not line or not line.startswith("STATUS "):
            raise StageError(f"bad STATUS reply: {line!r}")
        out = {}
        for tok in line[len("STATUS "):].split():
            k, _, v = tok.partition("=")
            if k == "angle":
                out[k] = float(v)
            elif k in ("steps", "v", "a", "settle", "res"):
                out[k] = int(v)
            else:
                out[k] = v
        return out
```

- [ ] **Step 4: Run test to verify it passes**

Run: `.venv/Scripts/python.exe -m pytest tests/motion/test_stage.py -v`
Expected: PASS.

- [ ] **Step 5: Commit**

```bash
git add gemscanner/motion/stage.py tests/motion/test_stage.py
git commit -m "feat: RotaryStage client speaking the firmware protocol"
```

---

### Task 5: ScanController (step-and-settle)

**Files:**
- Create: `gemscanner/acquisition/__init__.py`
- Create: `gemscanner/acquisition/scan_controller.py`
- Test: `tests/acquisition/test_scan_controller.py`

**Interfaces:**
- Consumes: a `CameraBackend`, a `RotaryStage`, `storage.ScanManifest`, OpenCV (`cv2.imwrite`).
- Produces:
  - `ScanParams(n_views=180, mm_per_px=0.0288, axis_column=0.0, axis_tilt_rad=0.0, eccentricity_mm=None)`.
  - `ScanController(camera, stage)` with `run(out_dir, params) -> str` (returns `out_dir`). Captures `n_views` frames over 360° (frame 0 at the start angle, then `move_deg(360/n_views)` + capture, ×(n_views−1)), writes `out_dir/frames/NNNN.png` and `out_dir/manifest.json` via `ScanManifest`. **No per-frame re-centering.**

- [ ] **Step 1: Write the failing test**

```python
# tests/acquisition/test_scan_controller.py
import os
import numpy as np
from gemscanner.camera.mock import MockCamera
from gemscanner.motion.fake_firmware import FakeFirmware
from gemscanner.motion.stage import RotaryStage
from gemscanner.acquisition.scan_controller import ScanController, ScanParams
from gemscanner.storage.dataset import load_dataset

def test_run_writes_dataset(tmp_path):
    counter = {"n": 0}
    def provider():
        counter["n"] += 1
        return np.full((40, 40), counter["n"] % 256, np.uint8)
    cam = MockCamera(frame_provider=provider)
    stage = RotaryStage(FakeFirmware()); stage.set_resolution(36000)
    ctrl = ScanController(cam, stage)
    out = ctrl.run(str(tmp_path / "scan"),
                   ScanParams(n_views=12, mm_per_px=0.05, axis_column=20.0))
    ds = load_dataset(out)
    assert ds.frame_count() == 12
    assert ds.manifest.mm_per_px == 0.05
    assert ds.manifest.axis_column == 20.0
    assert len(ds.manifest.angles_deg) == 12
    assert abs(ds.manifest.angles_deg[1] - 30.0) < 1e-6   # 360/12
```

- [ ] **Step 2: Run test to verify it fails**

Run: `.venv/Scripts/python.exe -m pytest tests/acquisition/test_scan_controller.py -v`
Expected: FAIL (`ModuleNotFoundError`).

- [ ] **Step 3: Implement**

```python
# gemscanner/acquisition/__init__.py
```

```python
# gemscanner/acquisition/scan_controller.py
import os
from dataclasses import dataclass
import cv2
from gemscanner.storage.manifest import ScanManifest

@dataclass
class ScanParams:
    n_views: int = 180
    mm_per_px: float = 0.0288
    axis_column: float = 0.0
    axis_tilt_rad: float = 0.0
    eccentricity_mm: float = None

class ScanController:
    def __init__(self, camera, stage):
        self.camera = camera
        self.stage = stage

    def run(self, out_dir, params):
        os.makedirs(os.path.join(out_dir, "frames"), exist_ok=True)
        inc = 360.0 / params.n_views
        angles, files = [], []
        h = w = 0
        with self.camera:
            for i in range(params.n_views):
                if i > 0:
                    self.stage.move_deg(inc)
                frame = self.camera.grab()
                h, w = frame.shape[:2]
                fname = f"{i:04d}.png"
                cv2.imwrite(os.path.join(out_dir, "frames", fname), frame)
                files.append(f"frames/{fname}")
                angles.append(round(i * inc, 6))
        ScanManifest(
            angles_deg=angles, mm_per_px=params.mm_per_px,
            axis_column=params.axis_column, axis_tilt_rad=params.axis_tilt_rad,
            eccentricity_mm=params.eccentricity_mm,
            image_width=w, image_height=h, frame_files=files,
            metadata={"source": "ScanController"},
        ).save(os.path.join(out_dir, "manifest.json"))
        return out_dir
```

- [ ] **Step 4: Run test to verify it passes**

Run: `.venv/Scripts/python.exe -m pytest tests/acquisition/test_scan_controller.py -v`
Expected: PASS.

- [ ] **Step 5: Commit**

```bash
git add gemscanner/acquisition/__init__.py gemscanner/acquisition/scan_controller.py tests/acquisition/test_scan_controller.py
git commit -m "feat: step-and-settle ScanController writing a Plan A dataset"
```

---

### Task 6: Pre-scan FoV / eccentricity check

**Files:**
- Create: `gemscanner/acquisition/prescan.py`
- Test: `tests/acquisition/test_prescan.py`

**Interfaces:**
- Consumes: a `CameraBackend`, a `RotaryStage`, `vision.silhouette.extract_silhouette`, `coords.column_to_projection`.
- Produces:
  - `PrescanResult(ok: bool, offending_angle: float | None, eccentricity_mm: float, touched_border: bool)`.
  - `prescan_fov_check(camera, stage, axis_column, mm_per_px, n_probe=12, threshold=None, margin_px=2) -> PrescanResult`. Rotates through `n_probe` equal steps over 360°, extracts each silhouette, flags clipping if the silhouette's bounding columns/rows come within `margin_px` of any frame border (records the first offending angle), and estimates eccentricity from the half-swing of the silhouette-centroid column about `axis_column` (in mm). Restores the stage to start with a final complementary move.

- [ ] **Step 1: Write the failing test**

```python
# tests/acquisition/test_prescan.py
import numpy as np
from gemscanner.camera.mock import MockCamera
from gemscanner.motion.fake_firmware import FakeFirmware
from gemscanner.motion.stage import RotaryStage
from gemscanner.acquisition.prescan import prescan_fov_check

def _disc(w, h, cx, r):
    img = np.full((h, w), 255, np.uint8)
    yy, xx = np.ogrid[:h, :w]
    img[(xx - cx) ** 2 + (yy - h // 2) ** 2 <= r * r] = 0
    return img

def test_centered_object_passes():
    frames = [_disc(200, 200, 100, 20) for _ in range(6)]
    cam = MockCamera(frames=frames)
    stage = RotaryStage(FakeFirmware()); stage.set_resolution(36000)
    res = prescan_fov_check(cam, stage, axis_column=100.0, mm_per_px=0.05, n_probe=6)
    assert res.ok and not res.touched_border

def test_object_touching_border_flags():
    frames = [_disc(200, 200, 195, 20)]   # disc runs off the right edge
    cam = MockCamera(frames=frames)
    stage = RotaryStage(FakeFirmware()); stage.set_resolution(36000)
    res = prescan_fov_check(cam, stage, axis_column=100.0, mm_per_px=0.05, n_probe=1)
    assert not res.ok and res.touched_border
```

- [ ] **Step 2: Run test to verify it fails**

Run: `.venv/Scripts/python.exe -m pytest tests/acquisition/test_prescan.py -v`
Expected: FAIL (`ModuleNotFoundError`).

- [ ] **Step 3: Implement**

```python
# gemscanner/acquisition/prescan.py
from dataclasses import dataclass
import numpy as np
from gemscanner.vision.silhouette import extract_silhouette
from gemscanner.coords import column_to_projection

@dataclass
class PrescanResult:
    ok: bool
    offending_angle: float
    eccentricity_mm: float
    touched_border: bool

def prescan_fov_check(camera, stage, axis_column, mm_per_px,
                      n_probe=12, threshold=None, margin_px=2):
    inc = 360.0 / n_probe
    touched = False
    offending = None
    centroid_cols = []
    with camera:
        for i in range(n_probe):
            if i > 0:
                stage.move_deg(inc)
            mask = extract_silhouette(camera.grab(), threshold)
            ys, xs = np.where(mask)
            if xs.size == 0:
                continue
            h, w = mask.shape
            if (xs.min() <= margin_px or xs.max() >= w - 1 - margin_px or
                    ys.min() <= margin_px or ys.max() >= h - 1 - margin_px):
                touched = True
                if offending is None:
                    offending = round(i * inc, 3)
            centroid_cols.append(xs.mean())
        if n_probe > 1:
            stage.move_deg(inc)   # complete the revolution back to start
    if centroid_cols:
        swing_px = (max(centroid_cols) - min(centroid_cols)) / 2.0
        ecc = abs(column_to_projection(axis_column + swing_px, axis_column, mm_per_px))
    else:
        ecc = 0.0
    return PrescanResult(ok=not touched, offending_angle=offending,
                         eccentricity_mm=ecc, touched_border=touched)
```

- [ ] **Step 4: Run test to verify it passes**

Run: `.venv/Scripts/python.exe -m pytest tests/acquisition/test_prescan.py -v`
Expected: PASS.

- [ ] **Step 5: Commit**

```bash
git add gemscanner/acquisition/prescan.py tests/acquisition/test_prescan.py
git commit -m "feat: pre-scan FoV/eccentricity check"
```

---

### Task 7: Calibration math + persistence

**Files:**
- Create: `gemscanner/calibration/__init__.py`
- Create: `gemscanner/calibration/fit.py`
- Create: `gemscanner/calibration/calibration.py`
- Test: `tests/calibration/test_fit.py`
- Test: `tests/calibration/test_calibration.py`

**Interfaces:**
- Consumes: numpy.
- Produces:
  - `fit_rotation_axis(angles_deg, centroid_cols) -> (axis_column, amplitude)` — least-squares fit of `u(θ) = c + a·cosθ + b·sinθ`; returns `c` and `hypot(a, b)`.
  - `mm_per_px_from_gauge(measured_px, known_mm) -> float`.
  - `steps_per_rev_from(motor_steps, microstep, gear_ratio) -> int`.
  - `Calibration` dataclass (`mm_per_px`, `axis_column`, `axis_tilt_rad=0.0`, `steps_per_rev=0`, `eccentricity_mm=None`) with `save(path)`/`load(path)` (JSON).

- [ ] **Step 1: Write the failing tests**

```python
# tests/calibration/test_fit.py
import numpy as np
from gemscanner.calibration.fit import (
    fit_rotation_axis, mm_per_px_from_gauge, steps_per_rev_from)

def test_fit_recovers_axis_and_amplitude():
    angles = np.arange(0, 360, 10.0)
    c, A, phase = 128.5, 7.0, 0.6
    cols = c + A * np.cos(np.radians(angles) - phase)
    axis, amp = fit_rotation_axis(angles, cols)
    assert abs(axis - c) < 1e-6
    assert abs(amp - A) < 1e-6

def test_scale_and_steps():
    assert abs(mm_per_px_from_gauge(200, 10.0) - 0.05) < 1e-9
    assert steps_per_rev_from(500, 10, 18) == 90000
```

```python
# tests/calibration/test_calibration.py
from gemscanner.calibration.calibration import Calibration

def test_roundtrip(tmp_path):
    c = Calibration(mm_per_px=0.0288, axis_column=1223.5, steps_per_rev=90000)
    p = tmp_path / "cal.json"
    c.save(p)
    loaded = Calibration.load(p)
    assert loaded.steps_per_rev == 90000
    assert abs(loaded.mm_per_px - 0.0288) < 1e-12
```

- [ ] **Step 2: Run tests to verify they fail**

Run: `.venv/Scripts/python.exe -m pytest tests/calibration -v`
Expected: FAIL (`ModuleNotFoundError`).

- [ ] **Step 3: Implement**

```python
# gemscanner/calibration/__init__.py
```

```python
# gemscanner/calibration/fit.py
import numpy as np

def fit_rotation_axis(angles_deg, centroid_cols):
    th = np.radians(np.asarray(angles_deg, float))
    u = np.asarray(centroid_cols, float)
    A = np.column_stack([np.ones_like(th), np.cos(th), np.sin(th)])
    c, a, b = np.linalg.lstsq(A, u, rcond=None)[0]
    return float(c), float(np.hypot(a, b))

def mm_per_px_from_gauge(measured_px, known_mm):
    return known_mm / measured_px

def steps_per_rev_from(motor_steps, microstep, gear_ratio):
    return int(round(motor_steps * microstep * gear_ratio))
```

```python
# gemscanner/calibration/calibration.py
from dataclasses import dataclass, asdict
import json

@dataclass
class Calibration:
    mm_per_px: float
    axis_column: float
    axis_tilt_rad: float = 0.0
    steps_per_rev: int = 0
    eccentricity_mm: float = None

    def save(self, path):
        with open(path, "w", encoding="utf-8") as f:
            json.dump(asdict(self), f, indent=2)

    @classmethod
    def load(cls, path):
        with open(path, encoding="utf-8") as f:
            return cls(**json.load(f))
```

- [ ] **Step 4: Run tests to verify they pass**

Run: `.venv/Scripts/python.exe -m pytest tests/calibration -v`
Expected: PASS.

- [ ] **Step 5: Commit**

```bash
git add gemscanner/calibration tests/calibration
git commit -m "feat: calibration math (axis fit, scale, steps-per-rev) and persistence"
```

---

### Task 8: CLI + Open3D viewer

**Files:**
- Create: `gemscanner/viewer.py`
- Create: `gemscanner/cli.py`
- Test: `tests/test_viewer.py`
- Test: `tests/test_cli.py`

**Interfaces:**
- Consumes: `open3d`, `trimesh`, `reconstruction.pipeline.reconstruct_dataset`, `storage.mesh_io.export_mesh`.
- Produces:
  - `viewer.trimesh_to_open3d(mesh) -> o3d.geometry.TriangleMesh` (headless-constructible); `viewer.show_mesh(mesh_or_path)` (opens a window — bench).
  - `cli.main(argv=None) -> int` with subcommands: `reconstruct <dataset> -o <mesh>` (host), `view <mesh>` (bench window), `scan -c <config>` / `calibrate` (bench).

- [ ] **Step 1: Write the failing tests**

```python
# tests/test_viewer.py
import trimesh
from gemscanner.viewer import trimesh_to_open3d

def test_conversion_preserves_counts():
    box = trimesh.creation.box(extents=(2, 2, 2))
    o3d_mesh = trimesh_to_open3d(box)
    assert len(o3d_mesh.vertices) == len(box.vertices)
    assert len(o3d_mesh.triangles) == len(box.faces)
```

```python
# tests/test_cli.py
import os
from gemscanner.synthetic.generator import generate_ellipsoid_scan
from gemscanner.cli import main

def test_reconstruct_subcommand(tmp_path):
    ds = generate_ellipsoid_scan(str(tmp_path / "scan"), rx=4, ry=3, rz=5,
                                 n_views=60, mm_per_px=0.05, width=200, height=200)
    out = tmp_path / "gem.stl"
    rc = main(["reconstruct", ds, "-o", str(out)])
    assert rc == 0
    assert os.path.exists(out)
```

- [ ] **Step 2: Run tests to verify they fail**

Run: `.venv/Scripts/python.exe -m pytest tests/test_viewer.py tests/test_cli.py -v`
Expected: FAIL (`ModuleNotFoundError`).

- [ ] **Step 3: Implement**

```python
# gemscanner/viewer.py
import numpy as np

def trimesh_to_open3d(mesh):
    import open3d as o3d
    m = o3d.geometry.TriangleMesh()
    m.vertices = o3d.utility.Vector3dVector(np.asarray(mesh.vertices, float))
    m.triangles = o3d.utility.Vector3iVector(np.asarray(mesh.faces, np.int32))
    m.compute_vertex_normals()
    return m

def show_mesh(mesh_or_path):
    import trimesh
    import open3d as o3d
    mesh = mesh_or_path if hasattr(mesh_or_path, "vertices") else trimesh.load(mesh_or_path)
    o3d.visualization.draw_geometries([trimesh_to_open3d(mesh)])
```

```python
# gemscanner/cli.py
import argparse
from gemscanner.reconstruction.pipeline import reconstruct_dataset
from gemscanner.storage.mesh_io import export_mesh

def main(argv=None):
    p = argparse.ArgumentParser(prog="gemscanner")
    sub = p.add_subparsers(dest="cmd", required=True)

    r = sub.add_parser("reconstruct")
    r.add_argument("dataset")
    r.add_argument("-o", "--out", required=True)

    v = sub.add_parser("view")
    v.add_argument("mesh")

    s = sub.add_parser("scan")
    s.add_argument("-c", "--config", required=True)
    s.add_argument("-o", "--out", required=True)

    args = p.parse_args(argv)

    if args.cmd == "reconstruct":
        mesh = reconstruct_dataset(args.dataset)
        export_mesh(mesh, args.out)
        print(f"wrote {args.out}: watertight={mesh.is_watertight}")
        return 0
    if args.cmd == "view":
        from gemscanner.viewer import show_mesh
        show_mesh(args.mesh)
        return 0
    if args.cmd == "scan":
        from gemscanner.run_scan import run_scan_from_config   # Task 12
        return run_scan_from_config(args.config, args.out)
    return 1
```

> Note: `gemscanner.run_scan` is created in Task 12 (bench wiring). The `scan` branch imports it lazily so `reconstruct`/`view` work before Task 12 exists.

- [ ] **Step 4: Run tests to verify they pass**

Run: `.venv/Scripts/python.exe -m pytest tests/test_viewer.py tests/test_cli.py -v`
Expected: PASS.

- [ ] **Step 5: Commit**

```bash
git add gemscanner/viewer.py gemscanner/cli.py tests/test_viewer.py tests/test_cli.py
git commit -m "feat: CLI (reconstruct/view/scan) and Open3D viewer"
```

---

### Task 9: End-to-end mock integration (scan → reconstruct)

**Files:**
- Create: `gemscanner/testing/scene_camera.py`
- Test: `tests/test_end_to_end_scan.py`

**Interfaces:**
- Consumes: `motion.fake_firmware.FakeFirmware`, `motion.stage.RotaryStage`, `acquisition.scan_controller`, `reconstruction.pipeline.reconstruct_dataset`, the Plan A ellipsoid projection math.
- Produces: `SceneCamera(stage_fw, rx, ry, rz, mm_per_px, width, height, center_offset=(0,0))` — a `CameraBackend` whose `grab()` renders the orthographic silhouette of a fixed ellipsoid **at the FakeFirmware's current angle** (`pos_steps / steps_per_rev`), so a `ScanController` run produces a physically-consistent silhouette stack.

- [ ] **Step 1: Write the failing test**

```python
# tests/test_end_to_end_scan.py
from gemscanner.motion.fake_firmware import FakeFirmware
from gemscanner.motion.stage import RotaryStage
from gemscanner.testing.scene_camera import SceneCamera
from gemscanner.acquisition.scan_controller import ScanController, ScanParams
from gemscanner.reconstruction.pipeline import reconstruct_dataset

def test_mock_scan_reconstructs_ellipsoid(tmp_path):
    fw = FakeFirmware()
    stage = RotaryStage(fw)
    stage.set_resolution(36000)
    cam = SceneCamera(fw, rx=4, ry=3, rz=5, mm_per_px=0.05, width=400, height=400)
    params = ScanParams(n_views=180, mm_per_px=0.05, axis_column=(400 - 1) / 2.0)
    out = ScanController(cam, stage).run(str(tmp_path / "scan"), params)
    mesh = reconstruct_dataset(out)
    ext = mesh.bounding_box.extents
    assert mesh.is_watertight
    assert abs(ext[0] - 8.0) < 0.4 and abs(ext[1] - 6.0) < 0.4 and abs(ext[2] - 10.0) < 0.4
```

- [ ] **Step 2: Run test to verify it fails**

Run: `.venv/Scripts/python.exe -m pytest tests/test_end_to_end_scan.py -v`
Expected: FAIL (`ModuleNotFoundError`).

- [ ] **Step 3: Implement**

```python
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

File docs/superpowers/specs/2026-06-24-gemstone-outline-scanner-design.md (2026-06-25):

# Gemstone Outline Scanner — Design Spec

**Date:** 2026-06-24
**Status:** Approved for planning
**Author:** GemScanner project

## 1. Purpose

Build a desktop application that reconstructs a 3D model of a gemstone from its
**silhouette outlines** captured at many rotation angles (shape-from-silhouette /
visual hull). A gemstone mounted on a motorized rotary stage is backlit by a
collimated source and imaged through a telecentric lens, giving an **orthographic**
(parallel-ray) projection. The app drives a **step-and-settle** scan over 360°,
extracts the silhouette at each angle, and reconstructs a watertight 3D mesh for
export and inspection.

## 2. Hardware

| Item | Part | Role |
|---|---|---|
| Lens | TVS-5MDT0.12×250 (C-mount telecentric) | Orthographic, magnification-stable imaging |
| Camera (primary) | Baumer EXG50 (GigE Vision, 5 MP, ~3.45 µm pixels) | Silhouette capture via GenICam/neoAPI |
| Camera (future) | Generic USB camera on the same lens | Alternate backend, config-selectable |
| Backlight | Collimated / telecentric backlight | Crisp, magnification-stable silhouette edges |
| Rotary stage | SURUGA SEIKI KRW06360 | Gemstone rotation about a vertical axis |
| Motor | Oriental Motor C005C-9021 5P-1 (5-phase stepper) | Drives the stage |
| Driver | Oriental Motor **ADB-5331A** (5-phase) | STEP/DIR/ENABLE → motor windings |
| Controller | Waveshare ESP32-C6-LCD-1.47 | Motion control + status LCD, USB-CDC link to PC |
| Host | Windows 11 PC | Runs the Python application |
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

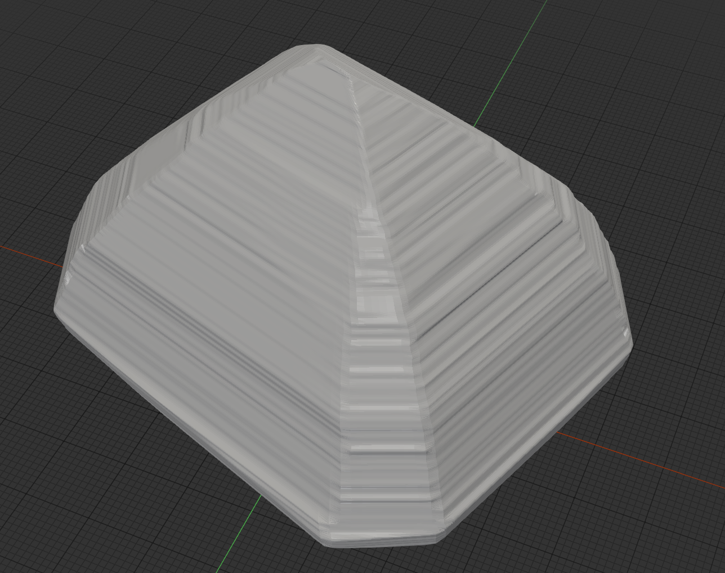
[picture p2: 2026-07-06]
docs/gemStrikeMarks.png

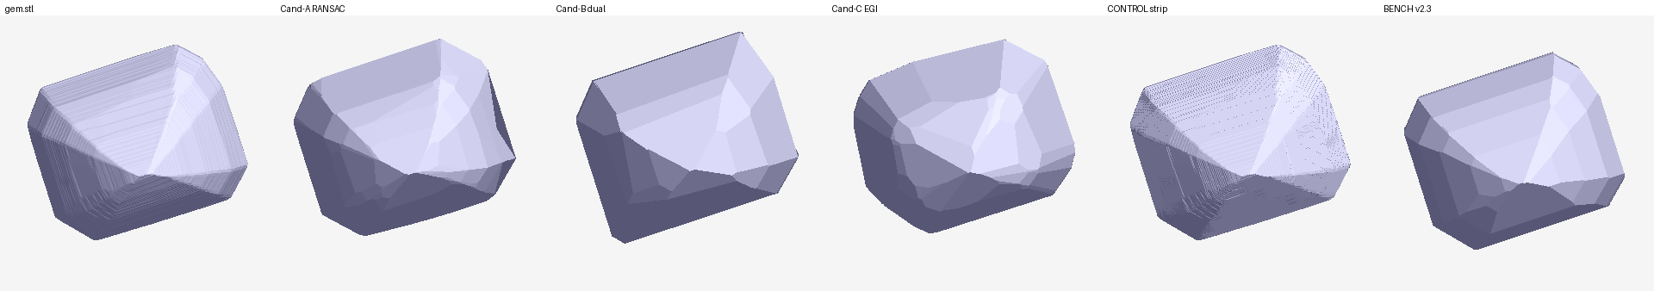
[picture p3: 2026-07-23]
scratchpad/cleanroom/bakeoff_gem04.png

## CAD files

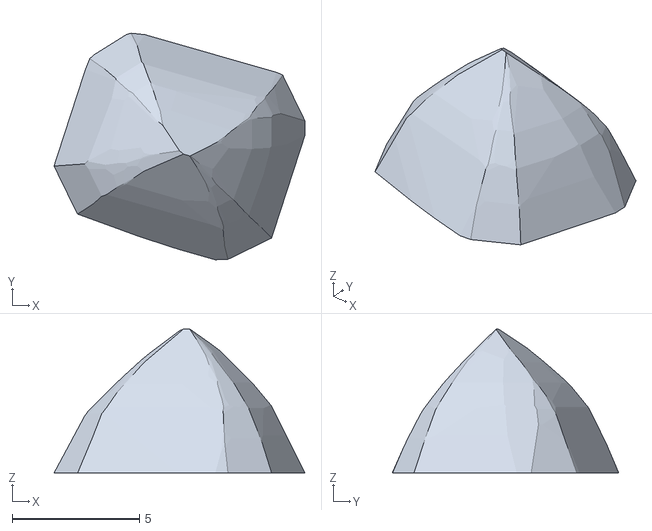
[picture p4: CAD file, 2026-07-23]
scratchpad/cleanroom/cand_a_gem04.stl
9.87 x 8.91 x 5.66

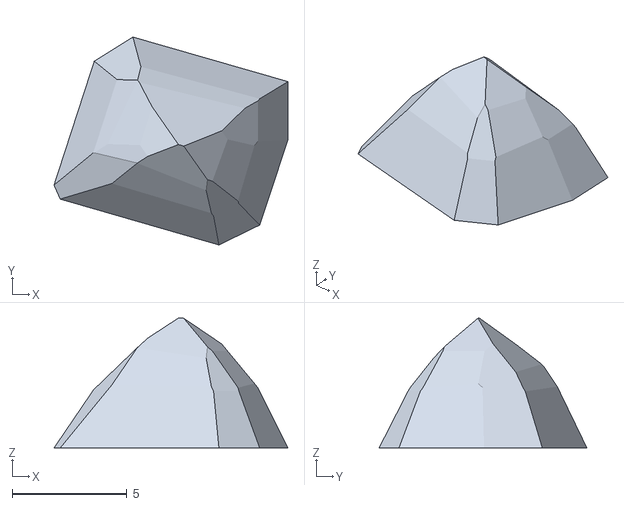
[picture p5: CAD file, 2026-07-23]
scratchpad/cleanroom/cand_b_gem04.stl
10.2 x 9.05 x 5.65

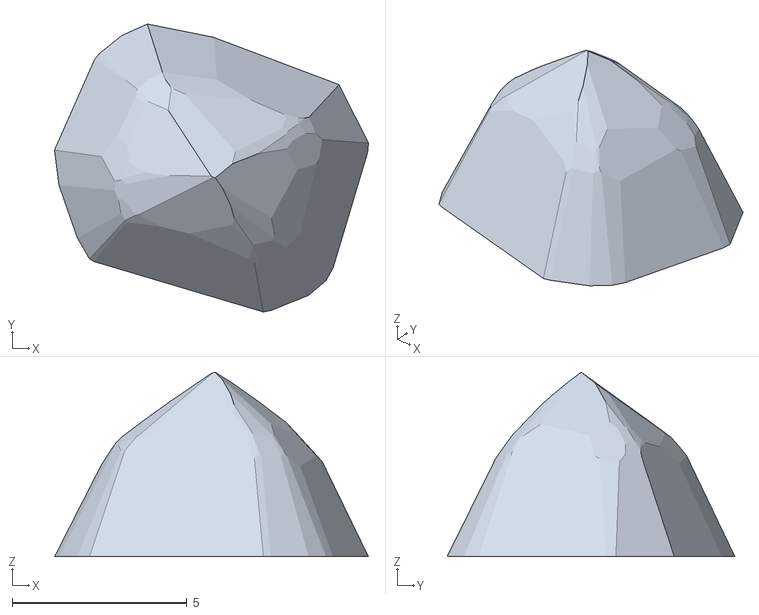
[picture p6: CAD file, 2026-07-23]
scratchpad/cleanroom/cand_c_gem04.stl
8.98 x 8.24 x 5.27

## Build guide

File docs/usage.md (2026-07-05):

# GemScanner — day-to-day usage

Run everything from the repo root through the venv Python (`.venv\Scripts\python.exe`).
Config and calibration live in `config.example.yaml` (also the default working config)
and `calibration.json`.

> **Before any camera command:** close **Camera Explorer** (`bexplorer`) — only one
> app can hold the GigE camera at a time.

## Grab a single image

Grabbing is a bench *script* (not a CLI subcommand). It uses the camera settings from
the config (exposure, gain) unless overridden.

```powershell
.venv\Scripts\python.exe scripts\grab.py -o grab.png          # config exposure/gain
.venv\Scripts\python.exe scripts\grab.py -e 500 -o grab.png   # override exposure (us)
Invoke-Item grab.png
```

It prints `min/max/mean` so you can judge exposure — aim for a solid-black gem
(min near 0) on a bright background (~200–250).

## Start a new scan

```powershell
# prescan FoV check -> 180-view capture -> reconstruct -> scans\<name>\gem.stl
.venv\Scripts\python.exe -m gemscanner.cli scan -c config.example.yaml -o scans\gem03

# view the result
.venv\Scripts\python.exe -m gemscanner.cli view scans\gem03\gem.stl

# override mesh smoothing for this run (config default scan.smooth=10; 0 = raw hull)
.venv\Scripts\python.exe -m gemscanner.cli scan -c config.example.yaml -o scans\gem03 --smooth 0
```

## Reconstruct / view an existing dataset

```powershell
.venv\Scripts\python.exe -m gemscanner.cli reconstruct scans\gem03 -o out.stl --smooth 10
.venv\Scripts\python.exe -m gemscanner.cli view out.stl
```

## Scanning a *different* gem

`mm_per_px` and `steps_per_rev` carry over (same pedestal + motor), but the per-gem
geometry must be redone or the mesh will be skewed / include the pedestal:

```powershell
# 1. grab a frame; find the gem/pedestal junction row, then set
#    scan.holder_mask_rows = 1944 - junction_row  in config.example.yaml
.venv\Scripts\python.exe scripts\grab.py -o grab.png

# 2. re-fit the rotation axis for the new gem (one revolution)
.venv\Scripts\python.exe scripts\calibrate_axis.py -n 12 --write

# 3. scan (as above)
```

Full bench bring-up / calibration order is in [`scripts/README.md`](../scripts/README.md).

## Config knobs (`config.example.yaml`)

| Key | Meaning |
|-----|---|
| `camera.exposure_us` | Exposure in µs. 500 with the collimated backlight (short avoids light leaking through the gem). |
| `camera.gain` | Sensor gain. |
| `scan.n_views` | Frames per 360° (180 default). More views only round the cross-sections; they don't fix vertical layering. |
| `scan.holder_mask_rows` | Bottom image rows to mask out (drops pedestal + stage below the gem). Per-gem: `1944 − junction_row`. |
| `scan.smooth` | Taubin smoothing iterations on the final mesh (0 = off; ~10 removes per-slice layering without shrinking). |
| `scan.settle_ms` | Post-move settle before capture. |

## GUI

Launch the guided GUI (dark theme; live preview + per-gem wizard + batch queue):

    .venv/Scripts/python.exe -m gemscanner.cli gui -p project.example.yaml

Per gem: mount → align (exposure/gain + silhouette overlay, aim for gem `min≈0`
on a bright background) → drag the holder-mask line to the gem/pedestal junction →
Calibrate axis → Scan → Reconstruct. Then select the next gem in the queue and
repeat. Close Camera Explorer (`bexplorer`) first — only one app can hold the GigE camera.

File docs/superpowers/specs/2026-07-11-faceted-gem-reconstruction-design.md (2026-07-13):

# Faceted-Gem Reconstruction (unsupervised facet-plane recovery)

**Date:** 2026-07-11
**Status:** Design approved, pending spec review → implementation plan
**Scope:** A new, user-selectable reconstruction method that turns a turntable
silhouette scan of a *convex faceted* gemstone into a clean flat-faceted
polyhedron — real facets, sharp edges, exact meet-points — with **no** terracing
or reconstruction artifacts.

---

## 1. Problem

The existing pipeline (`strip_intersection` → `mesh.loft_slices_to_mesh`) builds a
turntable **visual hull** by carving each image row's cross-section independently
and lofting the stacked rings. Because rows are carved independently, sloped
surfaces show horizontal "terracing" / strike-lines. The shipped de-terracing
options (`edge_median_rows`, `axial_median_rows`, `soft_hull`) *denoise* this
wobble but never recover the underlying **flat facets** or the **sharp lines and
points where facets meet**. See `[[gemscanner-striation-fix]]`.

For a **faceted** stone we can do better than denoising: we can recover the
actual facet planes and rebuild the stone as the polyhedron they define.

## 2. Key insight — faceting is exactly solvable from the support function

A cut gemstone is (essentially always) a **convex polyhedron**. Silhouette
carving can only ever recover the convex hull anyway, so this assumption costs
nothing. Two consequences:

1. **Every facet is a supporting plane of the hull.** It appears as a straight
   tangent segment of the silhouette in the views where it faces grazing.
2. **Given the facet planes, everything else is exact and free.** Intersecting
   the facet half-spaces yields a watertight convex polytope; its **edges are
   where 2 planes meet** and its **meet-points are where ≥3 planes meet**. Flat
   by construction — no terracing, no re-meshing.

So the problem reduces from *"find edges on a noisy mesh"* to **"recover the set
of facet planes."** Edges and meet-points then fall out of the plane arrangement.

### 2.1 The support-function formulation (the crux)

`strip_intersection` already measures, per view `i` (angle `θ_i`) and per height
`z`, how far the silhouette tangent reaches. In the code's convention the slice
at height `z` satisfies `pmin(i,z) ≤ n_i · (x,y) ≤ pmax(i,z)` with
`n_i = (cos θ_i, −sin θ_i)`. Therefore:

- `H_right(i, z) = pmax(i, z)` = 2D support of the slice in direction `+n_i`
- `H_left(i, z)  = −pmin(i, z)` = 2D support in direction `−n_i`

Stacked over all `i` and `z`, `H` **is the support function of the convex stone**
sampled on horizontal directions, resolved per height. (`H_left(i,·)` equals
`H_right(i+180°, ·)` — a built-in redundancy/calibration check.)

Now take a facet plane with unit outward normal `(a, b, c)` and offset `d`:
`a·x + b·y + c·z = d`, body on the `≤ d` side. Let `m = √(a²+b²)`. At height `z`
the facet contributes a slice edge with 2D outward normal `(a, b)/m`, active in
the single view whose `n_i = (a, b)/m`. At that view:

```
H_right(i*, z) = (d − c·z) / m  =  β + α·z      with  α = −c/m ,  β = d/m
```

**A facet is edge-on in exactly one azimuth, and there its support is an affine
(straight) function of height `z`.** From that one affine fit the whole plane is
recovered exactly (`i*` gives azimuth, unit-normalize with `m²+c² = 1`):

```
m = 1/√(1+α²)              c = −α/√(1+α²)
a =  m·cos θ_{i*}          b = −m·sin θ_{i*}        d = β·m
```

Facet families in this single model:
- **Girdle / vertical facets** (`c ≈ 0`): `α ≈ 0` → support constant in `z`.
- **Crown / pavilion facets** (inclined): general `α`. Captured cleanly.
- **Table / culet** (near-axial normal, `m ≈ 0`): edge-on in *no* horizontal
  view. A single vertical turntable axis only samples horizontal view
  directions, so these are **not** recoverable from tangents. They are recovered
  separately as the **extreme-z horizontal plateaus** (top = table, bottom =
  culet). This is a fundamental limitation of single-axis turntable scanning and
  is handled explicitly, not left to fail.

For a convex stone, every non-axial facet is grazing-visible at its own azimuth,
and we sample all azimuths (180 views / 2°), so **completeness is achievable.**

## 3. Chosen approach — hybrid (approved)

- **Cut priors:** fully unsupervised (no cut type, no facet count).
- **Plane source:** hybrid — a smooth mesh *seeds* how many facets and their
  rough orientation (robust), then each plane is *refit against the raw
  silhouette support samples* (exact, artifact-free).
- **Convexity:** assumed (standard cuts; also the only thing silhouettes recover).

## 4. Pipeline — new `method="facet"`

New module `gemscanner/reconstruction/facet_fit.py`, dispatched from
`pipeline.reconstruct_dataset` (and the `StripIntersectionReconstructor`
neighbourhood) exactly like `soft_hull` is today.

1. **Support sampling.** Reuse the existing per-view carving to build the
   `H_right(i, z)` / `H_left(i, z)` support maps (mm), plus the per-view valid-z
   ranges. No new imaging code; this is the same `row_spans` → projection data
   already computed, retained as arrays instead of only consumed by clipping.

2. **Seed (mesh side of the hybrid).** Run the soft-hull reconstruction (smooth,
   terracing-free normals), then cluster its face normals on the Gauss sphere
   (area-weighted). Output: estimated **facet count** and each facet's rough
   `(azimuth, tilt)` and z-support window. Purpose: avoid over/under-
   segmentation and tell stage 3 where to look. The seed geometry is otherwise
   discarded.

3. **Refit (silhouette side).** For each seed facet, take the raw support
   samples in its azimuth window and its z-window and fit `H = β + α·z` by robust
   (Theil–Sen / RANSAC) regression. Refine the azimuth `i*` by minimizing the
   affine residual (sub-view-step). Convert `(θ_{i*}, α, β)` → exact
   `(a, b, c, d)`. Discard fits with too few inliers or excessive residual;
   merge planes that coincide within tolerance (rotational-symmetry duplicates).

4. **Table / culet.** Fit horizontal planes `z = z_max` (table) and `z = z_min`
   (culet) from the robust z-extents across all views. Include only if a genuine
   flat plateau exists (guards against a pointed culet, which is just a vertex).

5. **Assemble the polytope.** Intersect all facet half-spaces
   `{ x : a·x + b·y + c·z ≤ d }` into a convex polytope (half-space intersection
   about an interior point). Emit:
   - the watertight faceted **mesh** (each facet one planar polygon, fan- or
     ear-triangulated),
   - **edges** (adjacent-plane intersections) and **meet-points** (polytope
     vertices) as first-class outputs.

6. **Fallback.** If facet fitting is unstable — planarity residuals too high,
   facet count won't converge, or the assembled polytope loses volume vs the
   visual hull beyond tolerance — fall back to the currently-selected smooth
   method and surface a clear message ("stone does not appear cleanly faceted").

## 5. Data structures

```
FacetPlane:   normal (a,b,c) unit, offset d, azimuth θ*, (α, β),
              support/inlier count, rms residual (mm), source ∈ {tangent, extremal}
FacetModel:   planes: list[FacetPlane]
              polytope vertices (meet-points), edges (index pairs),
              face→vertex loops, per-facet planarity residual,
              symmetry order (detected), inter-facet angle table
```

`reconstruct(...)` still returns a `trimesh.Trimesh` (drop-in for callers/GUI);
`FacetModel` is attached (e.g. `mesh.metadata["facets"]`) and optionally written
alongside the STL for gemology (facet count, angles, symmetry).

## 6. Integration & outputs

- `ReconstructionParams`: add `method="facet"` plus a small number of tunables
  (`facet_min_inliers`, `facet_merge_deg`, `facet_planarity_tol_mm`,
  `facet_fallback=True`). Keep defaults conservative.
- `pipeline.reconstruct_dataset`: dispatch `method=="facet"` →
  `FacetReconstructor`, mirroring the existing `soft_hull` branch.
- **GUI:** a 5th `ReconstructionPanel` entry, **"Faceted gem (planar)"**, mapping
  to `method="facet"`. Global choice, consistent with the current panel.
- **Deps:** reuses `numpy`, `trimesh`, `scikit-image` (already required by
  soft-hull, used for the seed). Half-space intersection via `scipy.spatial`
  (`HalfspaceIntersection`/`ConvexHull`) — `scipy` is already an indirect dep;
  confirm and pin during planning. No new heavy dependency expected.

## 7. Validation

- **Synthetic faceted ground-truth (build first).** Extend the synthetic
  generator (today only `generate_ellipsoid_scan`) with
  `generate_polyhedron_scan(...)` that renders orthographic silhouettes of a
  *known* convex polyhedron (e.g. a parametric round-brilliant-like solid) using
  the existing projection/manifest conventions. This yields exact ground-truth
  planes / edges / meet-points, enabling unit tests that assert recovery to
  within tight tolerances (normals < ~0.5°, offsets < ~1 voxel). The ellipsoid
  generator cannot test faceting; this closes that gap.
- **Real scan: `scans/gem04`** (180 views / 2°, faceted; its `total` de-terracing
  metric is real facets per `[[gemscanner-striation-fix]]`). Measure:
  per-facet planarity residual (µm), edge sharpness, watertightness, facet count
  / symmetry plausibility, and overall dimensions vs the existing
  `scans/gem04/gem.stl`. Diameter/height must match the visual hull within the
  tolerance already established for the median methods (< ~1 µm bias expected;
  removal of terracing is near zero-mean).
- TDD throughout, matching the repo's existing test discipline.

## 8. Risks & mitigations

| Risk | Mitigation |
|---|---|
| Facet-count instability (over/under-segmentation) | Gauss-sphere seed + symmetry-aware merge; residual-gated acceptance |
| Girdle vs adjacent shallow facet ambiguity | Azimuth refine by affine-residual minimization; separate near-`α=0` handling |
| Axis / calibration error smears the affine fit | `H_left(i)` vs `H_right(i+180°)` redundancy check; robust regression |
| Table/culet not fittable from tangents | Explicit extremal-z horizontal-plane step; plateau guard |
| Stone not actually cleanly faceted (cabochon, worn) | Confidence gate → fallback to smooth method with a clear message |
| Half-space intersection degeneracy (near-parallel planes) | Merge within `facet_merge_deg`; interior-point solve; keep-largest safety |

## 9. Explicit non-goals (YAGNI)

- No non-convex / concave facet recovery (silhouettes can't see it; out of scope).
- No named-cut template fitting or cut identification (unsupervised only).
- No multi-axis / tilt-scanning to recover table/culet by tangent (hardware change).
- No change to capture, calibration, or the other reconstruction methods.

## 9a. Build order (approved)

Synthetic-GT-first, strict TDD:
1. `generate_polyhedron_scan(...)` + exact-recovery unit tests (planes/edges/
   meet-points to tight tolerance) — lock correctness before real data.
2. Support sampling + affine tangent fit (core `facet_fit.py`).
3. Gauss-sphere seed + refit + half-space assembly; fallback path.
4. gem04 tuning of acceptance thresholds; dimensional comparison vs `gem.stl`.
5. `ReconstructionParams`/pipeline wiring + GUI "Faceted gem (planar)".

## 10. Open items for the implementation plan

- Exact clustering method + threshold for the Gauss-sphere seed.
- Half-space intersection library choice (`scipy.spatial`) and interior-point
  seeding; degeneracy handling.
- Acceptance thresholds (inliers, residual, merge angle) — tune on gem04.
- Whether/how to persist `FacetModel` next to the STL, and any GUI surfacing of
  facet count / angles.

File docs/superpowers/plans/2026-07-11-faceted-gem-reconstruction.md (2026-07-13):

# Faceted-Gem Reconstruction Implementation Plan

> **For agentic workers:** REQUIRED SUB-SKILL: Use superpowers:subagent-driven-development (recommended) or superpowers:executing-plans to implement this plan task-by-task. Steps use checkbox (`- [ ]`) syntax for tracking.

**Goal:** Add an unsupervised, user-selectable `method="facet"` reconstruction that turns a turntable silhouette scan of a convex faceted gem into a clean flat-faceted polyhedron — real facets, sharp edges, exact meet-points, no terracing.

**Architecture:** The existing per-row carve already yields the stone's support function `H(view, z)`. Every facet is edge-on in one azimuth, where its support is affine in `z` (`H = β + α·z`); that fit recovers the exact plane. A smooth soft-hull mesh *seeds* facet count/orientation; each plane is *refit* on the raw support samples; the facet half-spaces are intersected into a watertight convex polytope whose edges/vertices are the facet edges/meet-points. Table/culet (near-axial normals) are recovered as extreme-z horizontal planes.

**Tech Stack:** Python 3.12, numpy, opencv (`cv2`), trimesh, scikit-image (soft-hull seed), scipy (`spatial.HalfspaceIntersection`, `optimize.linprog`), pytest. PySide6 for the GUI entry.

## Global Constraints

- Convex-stone assumption throughout; no concave/non-convex handling (out of scope).
- Fully unsupervised: no cut type, no facet count supplied by the user.
- Reuse existing conventions exactly: `coords.z_to_row` / `row_to_z`, `coords.column_to_projection` / `projection_to_column`, view normal `n_i = (cos θ_i, −sin θ_i)`, background 255 / silhouette 0, z=0 at image vertical centre.
- De-terracing math uses only `numpy` (repo convention: median filters avoid scipy); new facet math may use `scipy` (already an indirect dep — confirm/pin in Task 7).
- `reconstruct(...)` must keep returning a `trimesh.Trimesh` (drop-in for GUI/callers); facet metadata rides on `mesh.metadata["facets"]`.
- Strict TDD, bite-sized commits. Run the full suite (`pytest -q`) green before each commit that touches shared modules.
- Angle/offset tolerances for "exact recovery" on synthetic ground truth: normal error < 0.5°, offset error < 1 px (`mm_per_px`).

---

### Task 1: Synthetic polyhedron silhouette generator

Renders exact orthographic silhouettes of a *known* convex polyhedron about the vertical axis, so later tasks have ground truth. Orthographic silhouette of a convex solid = filled 2D convex hull of its projected vertices.

**Files:**
- Modify: `gemscanner/synthetic/generator.py` (add `generate_polyhedron_scan`)
- Test: `tests/synthetic/test_generator.py` (append)

**Interfaces:**
- Consumes: `coords.projection_to_column`, `coords.z_to_row`, `storage.manifest.ScanManifest`.
- Produces: `generate_polyhedron_scan(out_dir, vertices, n_views=180, mm_per_px=0.05, width=400, height=400) -> out_dir`. `vertices`: array-like `(N,3)` object-frame mm. Writes `frames/NNNN.png` + `manifest.json` (metadata `{"shape": "polyhedron", "n_vertices": N}`). Same axis/centre convention as `generate_ellipsoid_scan`.

- [ ] **Step 1: Write the failing test**

```python
# append to tests/synthetic/test_generator.py
from gemscanner.synthetic.generator import generate_polyhedron_scan

def _box_vertices(hx, hy, hz):
    import numpy as np
    return np.array([[sx*hx, sy*hy, sz*hz]
                     for sx in (-1, 1) for sy in (-1, 1) for sz in (-1, 1)], float)

def test_polyhedron_box_width_matches_extent(tmp_path):
    out = generate_polyhedron_scan(str(tmp_path / "box"), _box_vertices(4, 2, 5),
                                   n_views=4, mm_per_px=0.05, width=400, height=400)
    m = ScanManifest.load(os.path.join(out, "manifest.json"))
    assert len(m.frame_files) == 4
    img = cv2.imread(os.path.join(out, m.frame_files[0]), cv2.IMREAD_GRAYSCALE)  # theta=0
    dark_cols = np.where((img == 0).any(axis=0))[0]
    width_px = dark_cols[-1] - dark_cols[0] + 1
    # theta=0 sees the full 2*hx = 8 mm width => 8/0.05 = 160 px (within rounding)
    assert abs(width_px - 160) <= 2
    dark_rows = np.where((img == 0).any(axis=1))[0]
    height_px = dark_rows[-1] - dark_rows[0] + 1
    assert abs(height_px - 200) <= 2  # 2*hz = 10 mm => 200 px
```

- [ ] **Step 2: Run test to verify it fails**

Run: `pytest tests/synthetic/test_generator.py::test_polyhedron_box_width_matches_extent -v`
Expected: FAIL with `ImportError`/`cannot import name 'generate_polyhedron_scan'`.

- [ ] **Step 3: Write minimal implementation**

```python
# add to gemscanner/synthetic/generator.py (near the top imports it already has math, np, cv2)
from gemscanner.coords import z_to_row   # add to existing import line

def generate_polyhedron_scan(out_dir, vertices, n_views=180, mm_per_px=0.05,
                             width=400, height=400):
    """Render orthographic silhouettes of a convex polyhedron rotating about the
    vertical (z) axis. Silhouette = filled 2D convex hull of projected vertices.
    Background bright (255), silhouette dark (0)."""
    os.makedirs(os.path.join(out_dir, "frames"), exist_ok=True)
    vertices = np.asarray(vertices, dtype=float)
    axis_column = (width - 1) / 2.0
    angles = [i * 360.0 / n_views for i in range(n_views)]
    frame_files = []
    for i, ang in enumerate(angles):
        th = math.radians(ang)
        p = vertices[:, 0] * math.cos(th) - vertices[:, 1] * math.sin(th)  # horiz proj
        cols = projection_to_column(p, axis_column, mm_per_px)
        rows = z_to_row(vertices[:, 2], height, mm_per_px)
        pts = np.column_stack([cols, rows]).astype(np.float32)
        img = np.full((height, width), 255, dtype=np.uint8)
        hull = cv2.convexHull(pts)
        cv2.fillConvexPoly(img, hull.astype(np.int32), 0)
        fname = f"{i:04d}.png"
        cv2.imwrite(os.path.join(out_dir, "frames", fname), img)
        frame_files.append(f"frames/{fname}")
    manifest = ScanManifest(
        angles_deg=angles, mm_per_px=mm_per_px, axis_column=axis_column,
        axis_tilt_rad=0.0, image_width=width, image_height=height,
        frame_files=frame_files,
        metadata={"shape": "polyhedron", "n_vertices": int(len(vertices))},
    )
    manifest.save(os.path.join(out_dir, "manifest.json"))
    return out_dir
```

Note: `z_to_row` broadcasts over the vertex array (it is pure arithmetic on `z`).

- [ ] **Step 4: Run test to verify it passes**

Run: `pytest tests/synthetic/test_generator.py -v`
Expected: PASS (both new and existing generator tests).

- [ ] **Step 5: Commit**

```bash
git add gemscanner/synthetic/generator.py tests/synthetic/test_generator.py
git commit -m "feat(synthetic): orthographic silhouette generator for convex polyhedra"
```

---

### Task 2: Toy-gem builder + ground-truth facet planes

A parametric convex faceted solid (table + crown + girdle + pavilion + culet) and a helper that extracts its unique face planes. Gives later tasks exact ground-truth planes to score against.

**Files:**
- Create: `gemscanner/synthetic/toy_gem.py`
- Test: `tests/synthetic/test_toy_gem.py`

**Interfaces:**
- Consumes: `trimesh`.
- Produces:
  - `make_toy_gem(n=8, r_girdle=5.0, r_table=3.0, z_table=2.0, z_girdle_top=0.4, z_girdle_bottom=-0.4, z_culet=-4.0) -> (vertices (V,3) float, planes list[(normal (3,) unit, d float)])`. Solid: a girdle **band** — two `n`-gon rings at radius `r_girdle`, at `z_girdle_top` and `z_girdle_bottom` (this band creates the `n` **vertical** girdle facets); a smaller table polygon (radius `r_table`) at `z_table` (→ `n` crown + 1 table); a single apex culet at `z_culet` (→ `n` pavilion). Exactly `3n+1` distinct planes. Outward normals, body on `normal·x <= d` side.
  - `unique_face_planes(mesh, angle_tol_deg=1.0, offset_tol=1e-3) -> list[(normal (3,), d)]`: clusters a trimesh's coplanar triangles into distinct facet planes.

- [ ] **Step 1: Write the failing test**

```python
# tests/synthetic/test_toy_gem.py
import numpy as np
from gemscanner.synthetic.toy_gem import make_toy_gem, unique_face_planes

def test_toy_gem_has_all_four_facet_families():
    n = 8
    verts, planes = make_toy_gem(n=n)
    normals = np.array([p[0] for p in planes])
    # all normals unit length
    assert np.allclose(np.linalg.norm(normals, axis=1), 1.0, atol=1e-6)
    top = [p for p in planes if p[0][2] > 0.99]            # table, +z
    vertical = [p for p in planes if abs(p[0][2]) < 0.05]  # girdle, z~0
    crown = [p for p in planes if 0.05 <= p[0][2] <= 0.99] # tilted up
    pavilion = [p for p in planes if p[0][2] < -0.05]      # tilted down
    assert len(top) == 1
    assert len(vertical) == n
    assert len(crown) == n
    assert len(pavilion) == n
    assert len(planes) == 3 * n + 1     # all four families, nothing else

def test_unique_face_planes_dedupes_coplanar_triangles():
    verts, _ = make_toy_gem(n=6)
    import trimesh
    hull = trimesh.Trimesh(vertices=verts).convex_hull
    planes = unique_face_planes(hull)
    # a hexagonal toy gem: 1 table + 6 girdle + 6 crown + 6 pavilion = 19 distinct planes
    assert len(planes) == 19
```

- [ ] **Step 2: Run test to verify it fails**

Run: `pytest tests/synthetic/test_toy_gem.py -v`
Expected: FAIL with `ModuleNotFoundError: gemscanner.synthetic.toy_gem`.

- [ ] **Step 3: Write minimal implementation**

```python
# gemscanner/synthetic/toy_gem.py
"""Parametric convex faceted test solid + ground-truth plane extraction."""
import numpy as np
import trimesh

def make_toy_gem(n=8, r_girdle=5.0, r_table=3.0, z_table=2.0,
                 z_girdle_top=0.4, z_girdle_bottom=-0.4, z_culet=-4.0):
    """Return (vertices, planes) for a convex faceted 'toy gem'.

    Geometry: a girdle BAND (two n-gon rings at radius r_girdle, at
    z_girdle_top and z_girdle_bottom) gives n vertical girdle facets; a smaller
    table ring gives n crown facets + a table; a culet apex gives n pavilion
    facets. Same-radius rings make each girdle facet a vertical planar quad ->
    the convex hull has exactly 3n+1 distinct planes. planes are the unique
    outward face planes (normal unit, body on normal.x <= d)."""
    a = np.linspace(0, 2 * np.pi, n, endpoint=False)
    cos, sin = np.cos(a), np.sin(a)
    g_top = np.column_stack([r_girdle * cos, r_girdle * sin, np.full(n, z_girdle_top)])
    g_bot = np.column_stack([r_girdle * cos, r_girdle * sin, np.full(n, z_girdle_bottom)])
    table = np.column_stack([r_table * cos, r_table * sin, np.full(n, z_table)])
    culet = np.array([[0.0, 0.0, z_culet]])
    verts = np.vstack([g_top, g_bot, table, culet])
    hull = trimesh.Trimesh(vertices=verts).convex_hull
    planes = unique_face_planes(hull)
    return np.asarray(hull.vertices, float), planes

def unique_face_planes(mesh, angle_tol_deg=1.0, offset_tol=1e-3):
    """Cluster a convex mesh's triangles into distinct (normal, d) facet planes."""
    normals = np.asarray(mesh.face_normals, float)
    # signed offset d = normal . (any vertex of the face)
    tri0 = mesh.vertices[mesh.faces[:, 0]]
    d = np.einsum("ij,ij->i", normals, tri0)
    cos_tol = np.cos(np.radians(angle_tol_deg))
    out = []
    for nrm, off in zip(normals, d):
        for i, (kn, kd) in enumerate(out):
            if float(np.dot(nrm, kn)) >= cos_tol and abs(off - kd) <= offset_tol:
                break
        else:
            out.append((nrm / np.linalg.norm(nrm), float(off)))
    return out
```

- [ ] **Step 4: Run test to verify it passes**

Run: `pytest tests/synthetic/test_toy_gem.py -v`
Expected: PASS.

- [ ] **Step 5: Commit**

```bash
git add gemscanner/synthetic/toy_gem.py tests/synthetic/test_toy_gem.py
git commit -m "feat(synthetic): parametric toy-gem builder + unique face-plane extraction"
```

---

### Task 3: Support-map extraction from silhouettes

Expose the stone's support function `H(view, z)` as arrays — the raw material the facet fit consumes — reusing the existing carve inputs without changing `strip_intersection`'s behaviour.

**Files:**
- Create: `gemscanner/reconstruction/support.py`
- Test: `tests/reconstruction/test_support.py`

**Interfaces:**
- Consumes: `vision.silhouette.extract_silhouette` + `row_spans`, `coords.row_to_z`, `coords.axis_column_at_row`, `coords.column_to_projection`, `base.ReconstructionParams`.
- Produces: `support_maps(dataset, params=None) -> SupportMaps` dataclass with fields:
  - `z (H,) float` — object height per row (mm)
  - `theta (V,) float` — view angle per frame (rad)
  - `h_right (H, V) float` — support in `+n_i` (`= pmax`), NaN where row empty
  - `h_left  (H, V) float` — support in `−n_i` (`= −pmin`), NaN where row empty
  - `valid (H, V) bool`

- [ ] **Step 1: Write the failing test**

```python
# tests/reconstruction/test_support.py
import numpy as np
from gemscanner.synthetic.generator import generate_polyhedron_scan
from gemscanner.storage.dataset import load_dataset
from gemscanner.reconstruction.support import support_maps

def _box(hx, hy, hz):
    return np.array([[sx*hx, sy*hy, sz*hz]
                     for sx in (-1, 1) for sy in (-1, 1) for sz in (-1, 1)], float)

def test_support_of_box_is_half_width_at_theta0(tmp_path):
    out = generate_polyhedron_scan(str(tmp_path / "box"), _box(4, 2, 5),
                                   n_views=4, mm_per_px=0.05, width=400, height=400)
    sm = support_maps(load_dataset(out))
    # theta=0 view: support in +x is hx = 4 mm, over the box's z-range
    col = np.nanmedian(sm.h_right[:, 0])
    assert abs(col - 4.0) <= 0.05        # within one pixel (mm_per_px)
    # rows outside the box are invalid
    assert sm.valid.any() and not sm.valid.all()
```

- [ ] **Step 2: Run test to verify it fails**

Run: `pytest tests/reconstruction/test_support.py -v`
Expected: FAIL with `ModuleNotFoundError: gemscanner.reconstruction.support`.

- [ ] **Step 3: Write minimal implementation**

```python
# gemscanner/reconstruction/support.py
import math
from dataclasses import dataclass
import numpy as np
from gemscanner.coords import row_to_z, axis_column_at_row, column_to_projection
from gemscanner.vision.silhouette import extract_silhouette, row_spans
from gemscanner.reconstruction.base import ReconstructionParams

@dataclass
class SupportMaps:
    z: np.ndarray          # (H,)
    theta: np.ndarray      # (V,)
    h_right: np.ndarray    # (H, V)
    h_left: np.ndarray     # (H, V)
    valid: np.ndarray      # (H, V) bool

def support_maps(dataset, params=None):
    params = params if params is not None else ReconstructionParams()
    m = dataset.manifest
    H, mmpp = m.image_height, m.mm_per_px
    V = dataset.frame_count()

    z = np.array([row_to_z(v, H, mmpp) for v in range(H)])
    theta = np.radians(np.asarray(m.angles_deg, float))
    h_right = np.full((H, V), np.nan)
    h_left = np.full((H, V), np.nan)

    for i in range(V):
        img = dataset.load_frame(i)
        mask = extract_silhouette(img, params.threshold, params.holder_mask_rows)
        spans = row_spans(mask)
        for v in range(H):
            L, R = spans[v]
            if L < 0:
                continue
            axc = axis_column_at_row(m.axis_column, m.axis_tilt_rad, v, H)
            pmin = column_to_projection(L, axc, mmpp)
            pmax = column_to_projection(R, axc, mmpp)
            h_right[v, i] = pmax
            h_left[v, i] = -pmin

    valid = ~np.isnan(h_right)
    return SupportMaps(z=z, theta=theta, h_right=h_right, h_left=h_left, valid=valid)
```

- [ ] **Step 4: Run test to verify it passes**

Run: `pytest tests/reconstruction/test_support.py -v`
Expected: PASS.

- [ ] **Step 5: Commit**

```bash
git add gemscanner/reconstruction/support.py tests/reconstruction/test_support.py
git commit -m "feat(reconstruction): support-map extraction H(view,z) from silhouettes"
```

---

### Task 4: Affine tangent fit → exact plane recovery (pure math)

The crux math, isolated and unit-tested: fit `H = β + α·z` robustly, and convert a `(θ*, α, β)` triple into an exact unit plane `(a,b,c,d)`.

**Files:**
- Create: `gemscanner/reconstruction/facet_fit.py`
- Test: `tests/reconstruction/test_facet_fit.py`

**Interfaces:**
- Consumes: `numpy`.
- Produces:
  - `plane_from_affine(theta_star, alpha, beta) -> (a, b, c, d)` unit normal + offset, using `m=1/√(1+α²)`, `c=−α/√(1+α²)`, `a=m·cosθ*`, `b=−m·sinθ*`, `d=β·m` (matches `n_i=(cosθ,−sinθ)`).
  - `fit_affine_support(z, h, mask, min_inliers=8, resid_tol_mm=0.05) -> (alpha, beta, rms, n_inliers)`: robust (Theil–Sen slope + median intercept, then one inlier-trim + refit). Returns `alpha=nan` if fewer than `min_inliers` valid points.

- [ ] **Step 1: Write the failing test**

```python
# tests/reconstruction/test_facet_fit.py
import numpy as np
from gemscanner.reconstruction.facet_fit import plane_from_affine, fit_affine_support

def test_plane_from_affine_vertical_facet():
    # alpha=0 => vertical facet (c=0); theta*=0 => normal +x
    a, b, c, d = plane_from_affine(0.0, alpha=0.0, beta=5.0)
    assert np.allclose([a, b, c, d], [1.0, 0.0, 0.0, 5.0], atol=1e-9)

def test_plane_from_affine_45deg():
    # a 45-degree facet facing +x: normal ~ (cos45,0,sin45) with c>0 => alpha<0
    a, b, c, d = plane_from_affine(0.0, alpha=-1.0, beta=3.0)
    assert np.allclose([a, b, c], [np.sqrt(0.5), 0.0, np.sqrt(0.5)], atol=1e-9)
    assert np.isclose(a*a + b*b + c*c, 1.0)
    # d = beta*m with m=1/sqrt(2); verifies the d-scaling (m!=1 here)
    assert np.isclose(d, 3.0 / np.sqrt(2.0))

def test_fit_affine_robust_to_outliers():
    z = np.linspace(-4, 4, 60)
    h = 2.0 + 0.5 * z
    h[10] += 3.0; h[40] -= 2.5           # terracing-style outliers
    mask = np.ones_like(z, bool)
    alpha, beta, rms, n = fit_affine_support(z, h, mask)
    assert abs(alpha - 0.5) < 0.02 and abs(beta - 2.0) < 0.05
    assert n >= 50
    assert rms < 0.01                    # rms scoped to inliers, not outliers
```

- [ ] **Step 2: Run test to verify it fails**

Run: `pytest tests/reconstruction/test_facet_fit.py -v`
Expected: FAIL with `ModuleNotFoundError`.

- [ ] **Step 3: Write minimal implementation**

```python
# gemscanner/reconstruction/facet_fit.py
import numpy as np

def plane_from_affine(theta_star, alpha, beta):
    """(theta*, alpha, beta) -> unit plane (a,b,c,d), a*x+b*y+c*z = d.
    Support of an edge-on facet: H(z) = beta + alpha*z with alpha=-c/m,
    beta=d/m, m=sqrt(a^2+b^2). Convention n_i=(cos th, -sin th)."""
    m = 1.0 / np.sqrt(1.0 + alpha * alpha)
    c = -alpha * m
    a = m * np.cos(theta_star)
    b = -m * np.sin(theta_star)
    d = beta * m
    return float(a), float(b), float(c), float(d)

def _theilsen(z, h):
    n = len(z)
    if n < 2:
        return np.nan, np.nan
    # median of pairwise slopes (subsample pairs when large to stay cheap)
    idx = np.arange(n)
    if n > 120:
        idx = np.linspace(0, n - 1, 120).astype(int)
    zz, hh = z[idx], h[idx]
    dz = zz[:, None] - zz[None, :]
    dh = hh[:, None] - hh[None, :]
    ok = np.abs(dz) > 1e-9
    if not ok.any():                 # all z identical (degenerate) -> no slope
        return np.nan, np.nan
    slope = np.median(dh[ok] / dz[ok])
    intercept = np.median(hh - slope * zz)
    return float(slope), float(intercept)

def fit_affine_support(z, h, mask, min_inliers=8, resid_tol_mm=0.05):
    """Robust affine fit H=beta+alpha*z over masked/valid samples.
    Returns (alpha, beta, rms, n_inliers); alpha=nan if too few points."""
    z = np.asarray(z, float); h = np.asarray(h, float)
    sel = np.asarray(mask, bool) & np.isfinite(h)
    if sel.sum() < min_inliers:
        return np.nan, np.nan, np.nan, int(sel.sum())
    zz, hh = z[sel], h[sel]
    alpha, beta = _theilsen(zz, hh)
    if np.isnan(alpha):
        return np.nan, np.nan, np.nan, int(sel.sum())
    resid = np.abs(hh - (beta + alpha * zz))
    keep = resid <= max(resid_tol_mm, np.median(resid) * 3)
    if keep.sum() >= min_inliers:
        zz, hh = zz[keep], hh[keep]              # scope fit + rms to inliers
        A = np.column_stack([zz, np.ones(len(zz))])
        (alpha, beta), *_ = np.linalg.lstsq(A, hh, rcond=None)
    fit = beta + alpha * zz
    rms = float(np.sqrt(np.mean((hh - fit) ** 2)))   # rms over inliers only
    return float(alpha), float(beta), rms, int(keep.sum())
```

- [ ] **Step 4: Run test to verify it passes**

Run: `pytest tests/reconstruction/test_facet_fit.py -v`
Expected: PASS.

- [ ] **Step 5: Commit**

```bash
git add gemscanner/reconstruction/facet_fit.py tests/reconstruction/test_facet_fit.py
git commit -m "feat(reconstruction): affine support fit + exact plane recovery math"
```

---

### Task 5: Gauss-sphere facet seeding

Cluster a smooth mesh's face normals into distinct facet orientations — telling the refit *how many* facets and *which azimuth* each lives at. Greedy angular clustering keeps it dependency-light and deterministic.

**Files:**
- Modify: `gemscanner/reconstruction/facet_fit.py` (add `seed_facets`)
- Test: `tests/reconstruction/test_facet_fit.py` (append)

**Interfaces:**
- Consumes: `trimesh` mesh (`.face_normals`, `.area_faces`).
- Produces: `seed_facets(mesh, merge_deg=8.0, min_area_frac=0.005) -> list[dict]`, each `{"normal": (3,) unit, "azimuth": float rad, "tilt": float, "area": float}`, sorted by area desc. `azimuth = atan2(-b, a)` so it maps straight to a view angle under `n_i=(cosθ,−sinθ)`; `tilt = normal_z`.

- [ ] **Step 1: Write the failing test**

```python
# append to tests/reconstruction/test_facet_fit.py
from gemscanner.reconstruction.facet_fit import seed_facets
from gemscanner.synthetic.toy_gem import make_toy_gem
import trimesh

def test_seed_facets_recovers_distinct_orientations():
    verts, planes = make_toy_gem(n=8)
    hull = trimesh.Trimesh(vertices=verts).convex_hull
    seeds = seed_facets(hull, merge_deg=8.0)
    # ~ table(1) + girdle(8) + crown(8) + pavilion(8) distinct orientations
    assert 20 <= len(seeds) <= 30
    # a near +z table orientation is present
    assert any(s["normal"][2] > 0.95 for s in seeds)
    # azimuth maps back to the normal's horizontal direction
    for s in seeds[:5]:
        a, b = s["normal"][0], s["normal"][1]
        assert abs(np.cos(s["azimuth"]) - a / max(np.hypot(a, b), 1e-9)) < 1e-6
```

- [ ] **Step 2: Run test to verify it fails**

Run: `pytest tests/reconstruction/test_facet_fit.py::test_seed_facets_recovers_distinct_orientations -v`
Expected: FAIL with `ImportError: cannot import name 'seed_facets'`.

- [ ] **Step 3: Write minimal implementation**

```python
# add to gemscanner/reconstruction/facet_fit.py
def seed_facets(mesh, merge_deg=8.0, min_area_frac=0.005):
    """Cluster mesh face normals (area-weighted) into distinct facet seeds."""
    normals = np.asarray(mesh.face_normals, float)
    areas = np.asarray(mesh.area_faces, float)
    order = np.argsort(areas)[::-1]
    cos_tol = np.cos(np.radians(merge_deg))
    clusters = []   # each: [sum_area, accum_normal(weighted)]
    for i in order:
        n = normals[i]; w = areas[i]
        for cl in clusters:
            ref = cl[1] / np.linalg.norm(cl[1])
            if float(np.dot(n, ref)) >= cos_tol:
                cl[0] += w; cl[1] += w * n
                break
        else:
            clusters.append([w, w * n.copy()])
    total = float(areas.sum())
    seeds = []
    for area_sum, accum in clusters:
        if area_sum < min_area_frac * total:
            continue
        nrm = accum / np.linalg.norm(accum)
        seeds.append({"normal": nrm,
                      "azimuth": float(np.arctan2(-nrm[1], nrm[0])),
                      "tilt": float(nrm[2]),
                      "area": float(area_sum)})
    seeds.sort(key=lambda s: s["area"], reverse=True)
    return seeds
```

- [ ] **Step 4: Run test to verify it passes**

Run: `pytest tests/reconstruction/test_facet_fit.py -v`
Expected: PASS (all facet_fit tests).

- [ ] **Step 5: Commit**

```bash
git add gemscanner/reconstruction/facet_fit.py tests/reconstruction/test_facet_fit.py
git commit -m "feat(reconstruction): Gauss-sphere facet seeding from a smooth mesh"
```

---

### Task 6: Plane recovery, half-space assembly, and the FacetReconstructor

Tie it together: for each seed, refit the exact plane on the raw support maps (with azimuth refinement); add table/culet; merge duplicates; intersect half-spaces into a watertight polytope; emit mesh + edges + meet-points. End-to-end synthetic test asserts near-exact recovery.

**Files:**
- Modify: `gemscanner/reconstruction/base.py:4-17` (add facet fields — needed by this task's code)
- Modify: `gemscanner/reconstruction/facet_fit.py` (add recovery, assembly, `FacetReconstructor`)
- Test: `tests/reconstruction/test_facet_reconstruct.py`

**Interfaces:**
- Consumes: `support_maps` (Task 3), `plane_from_affine`/`fit_affine_support`/`seed_facets` (Tasks 4–5), `soft_hull.SoftHullReconstructor` (seed mesh), `scipy.spatial.HalfspaceIntersection`, `scipy.optimize.linprog`, `trimesh`.
- Produces:
  - `ReconstructionParams` facet fields (see Step 1b) — consumed here and by Task 7's dispatch.
  - `recover_planes(sm, seeds, params) -> list[dict]`, each `{"plane": (a,b,c,d), "rms": float, "n_inliers": int, "source": "tangent"|"extremal"}`.
  - `planes_to_polytope(planes) -> (trimesh.Trimesh, vertices (K,3), edges (E,2) int)`.
  - `class FacetReconstructor: reconstruct(self, dataset, params=None) -> trimesh.Trimesh` with `mesh.metadata["facets"]` = `{"planes":..., "vertices":..., "edges":...}`.

- [ ] **Step 1a: Add the facet params (prereq for the code below)**

```python
# gemscanner/reconstruction/base.py — add to ReconstructionParams (after `method`)
    # facet method (method="facet"): unsupervised facet-plane recovery
    facet_min_inliers: int = 12
    facet_merge_deg: float = 6.0
    facet_view_search: int = 4
    facet_axial_cos: float = 0.95      # |normal_z| above this = table/culet, not tangent
    facet_fallback: bool = True
    # (facet_planarity_tol_mm was dropped in final-review cleanup as unused)
```

- [ ] **Step 1: Write the failing test**

```python
# tests/reconstruction/test_facet_reconstruct.py
import numpy as np
import trimesh
from gemscanner.synthetic.toy_gem import make_toy_gem, unique_face_planes
from gemscanner.synthetic.generator import generate_polyhedron_scan
from gemscanner.storage.dataset import load_dataset
from gemscanner.reconstruction.base import ReconstructionParams
from gemscanner.reconstruction.facet_fit import FacetReconstructor

def _min_normal_error_deg(recovered, gt):
    errs = []
    for nr in recovered:
        c = max(abs(float(np.dot(nr, g))) for g in gt)
        errs.append(np.degrees(np.arccos(min(1.0, c))))
    return np.array(errs)

def test_facet_reconstruction_matches_ground_truth(tmp_path):
    verts, gt_planes = make_toy_gem(n=8)
    gt_normals = [p[0] for p in gt_planes]
    out = generate_polyhedron_scan(str(tmp_path / "gem"), verts, n_views=180,
                                   mm_per_px=0.05, width=500, height=500)
    mesh = FacetReconstructor().reconstruct(load_dataset(out), ReconstructionParams())
    assert mesh.is_watertight
    rec_normals = [p[:3] / np.linalg.norm(p[:3])
                   for p in mesh.metadata["facets"]["planes"]]
    errs = _min_normal_error_deg(rec_normals, gt_normals)
    # every recovered non-axial facet matches some GT facet closely
    assert np.median(errs) < 1.0
    # volume within a few percent of the true solid
    truth = trimesh.Trimesh(vertices=verts).convex_hull
    assert abs(mesh.volume - truth.volume) / truth.volume < 0.05
    # meet-points and edges are populated
    assert len(mesh.metadata["facets"]["vertices"]) >= 6
    assert len(mesh.metadata["facets"]["edges"]) >= 9
```

- [ ] **Step 2: Run test to verify it fails**

Run: `pytest tests/reconstruction/test_facet_reconstruct.py -v`
Expected: FAIL with `ImportError: cannot import name 'FacetReconstructor'`.

- [ ] **Step 3: Write minimal implementation**

```python
# add to gemscanner/reconstruction/facet_fit.py
import trimesh
from scipy.spatial import HalfspaceIntersection
from scipy.optimize import linprog
from gemscanner.reconstruction.support import support_maps
from gemscanner.reconstruction.base import ReconstructionParams

def _nearest_view(theta, az):
    d = np.angle(np.exp(1j * (theta - az)))   # wrapped difference
    return int(np.argmin(np.abs(d)))

def recover_planes(sm, seeds, params):
    """Refit each seed to an exact plane on the raw support maps; add table/culet."""
    planes = []
    for s in seeds:
        if abs(s["tilt"]) > params.facet_axial_cos:      # near-axial -> extremal
            continue
        best = None
        i0 = _nearest_view(sm.theta, s["azimuth"])
        for di in range(-params.facet_view_search, params.facet_view_search + 1):
            i = (i0 + di) % len(sm.theta)
            alpha, beta, rms, n = fit_affine_support(
                sm.z, sm.h_right[:, i], sm.valid[:, i],
                min_inliers=params.facet_min_inliers)
            if np.isnan(alpha):
                continue
            if best is None or rms < best[0]:
                best = (rms, sm.theta[i], alpha, beta, n)
        if best is None:
            continue
        rms, th, alpha, beta, n = best
        planes.append({"plane": plane_from_affine(th, alpha, beta),
                       "rms": rms, "n_inliers": n, "source": "tangent"})
    # table (top) and culet (bottom) as extremal-z horizontal planes
    zval = sm.z[np.where(sm.valid.any(axis=1))[0]]
    if zval.size:
        planes.append({"plane": (0.0, 0.0, 1.0, float(zval.max())),
                       "rms": 0.0, "n_inliers": int(sm.valid.any(axis=1).sum()),
                       "source": "extremal"})
        planes.append({"plane": (0.0, 0.0, -1.0, float(-zval.min())),
                       "rms": 0.0, "n_inliers": int(sm.valid.any(axis=1).sum()),
                       "source": "extremal"})
    return _merge_planes(planes, params.facet_merge_deg)

def _merge_planes(planes, merge_deg, d_reltol=0.02):
    # d-tolerance is RELATIVE to gem scale (max |offset|) so merging works on
    # any-sized stone -- a fixed mm threshold would over/under-merge on gem04.
    cos_tol = np.cos(np.radians(merge_deg))
    scale = max((abs(p["plane"][3]) for p in planes), default=1.0) or 1.0
    d_tol = d_reltol * scale
    out = []
    for p in planes:
        a, b, c, d = p["plane"]; n = np.array([a, b, c])
        for q in out:
            qa, qb, qc, qd = q["plane"]
            if float(np.dot(n, [qa, qb, qc])) >= cos_tol and abs(d - qd) < d_tol:
                if p["rms"] < q["rms"]:
                    q.update(p)
                break
        else:
            out.append(dict(p))
    return out

def _interior_point(halfspaces):
    """Chebyshev centre: maximise the inscribed-ball radius via linprog."""
    A = halfspaces[:, :-1]; b = -halfspaces[:, -1]
    norm = np.linalg.norm(A, axis=1, keepdims=True)
    A_ub = np.hstack([A, norm])
    c = np.zeros(A.shape[1] + 1); c[-1] = -1.0     # maximise radius
    res = linprog(c, A_ub=A_ub, b_ub=b, bounds=[(None, None)] * A.shape[1] + [(0, None)])
    if not res.success or res.x is None or res.x[-1] <= 0:
        # no strictly-interior point => planes don't bound a closed region
        # (a facet is missing). Clean signal for the Task 7 fallback.
        raise ValueError("facet half-spaces do not bound an interior region")
    return res.x[:-1]

def planes_to_polytope(planes):
    """Intersect facet half-spaces (a*x+b*y+c*z <= d) into a convex polytope."""
    # scipy halfspace form: A x + b <= 0  =>  [a,b,c, -d]
    hs = np.array([[a, b, c, -d] for (a, b, c, d) in
                   [p["plane"] for p in planes]], float)
    interior = _interior_point(hs)
    hi = HalfspaceIntersection(hs, interior)
    pts = hi.intersections
    hull = trimesh.Trimesh(vertices=pts).convex_hull
    edges = hull.edges_unique
    return hull, np.asarray(hull.vertices, float), np.asarray(edges, int)

class FacetReconstructor:
    def reconstruct(self, dataset, params=None):
        params = params if params is not None else ReconstructionParams()
        from gemscanner.reconstruction.soft_hull import SoftHullReconstructor
        seed_mesh = SoftHullReconstructor().reconstruct(dataset, params)
        seeds = seed_facets(seed_mesh, merge_deg=params.facet_merge_deg)
        sm = support_maps(dataset, params)
        planes = recover_planes(sm, seeds, params)
        if len(planes) < 4:
            raise ValueError("facet recovery failed: too few planes")
        mesh, verts, edges = planes_to_polytope(planes)
        mesh.metadata["facets"] = {
            "planes": [p["plane"] for p in planes],
            "vertices": verts, "edges": edges}
        return mesh
```

Note: the `facet_*` params this code reads were added in Step 1a above.

- [ ] **Step 4: Run test to verify it passes**

Run: `pytest tests/reconstruction/test_facet_reconstruct.py -v`
Expected: PASS (watertight, median normal error < 1°, volume within 5%).

- [ ] **Step 5: Commit**

```bash
git add gemscanner/reconstruction/facet_fit.py tests/reconstruction/test_facet_reconstruct.py
git commit -m "feat(reconstruction): plane recovery + half-space assembly (FacetReconstructor)"
```

---

### Task 7: Params, pipeline dispatch, and graceful fallback

Wire `method="facet"` into `ReconstructionParams` and `pipeline.reconstruct_dataset`, with a fallback to the selected smooth method when the stone isn't cleanly faceted.

**Files:**
- Modify: `gemscanner/reconstruction/pipeline.py:9-12` (dispatch)
- Test: `tests/reconstruction/test_pipeline_facet.py`

**Interfaces:**
- Consumes: `FacetReconstructor` (Task 6), `SoftHullReconstructor`, `StripIntersectionReconstructor`, the `facet_*` params added in Task 6 Step 1a.
- Produces: `reconstruct_dataset(path, params)` dispatches `method=="facet"` → `FacetReconstructor`, falling back to strip/soft-hull on failure when `facet_fallback`.

- [ ] **Step 1: Write the failing test**

```python
# tests/reconstruction/test_pipeline_facet.py
import numpy as np
from gemscanner.synthetic.toy_gem import make_toy_gem
from gemscanner.synthetic.generator import (generate_polyhedron_scan,
                                            generate_ellipsoid_scan)
from gemscanner.reconstruction.base import ReconstructionParams
from gemscanner.reconstruction.pipeline import reconstruct_dataset

def test_pipeline_facet_method(tmp_path):
    verts, _ = make_toy_gem(n=8)
    out = generate_polyhedron_scan(str(tmp_path / "gem"), verts, n_views=180,
                                   mm_per_px=0.05, width=500, height=500)
    mesh = reconstruct_dataset(out, ReconstructionParams(method="facet"))
    assert mesh.is_watertight and "facets" in mesh.metadata

def test_pipeline_facet_falls_back_on_non_faceted(tmp_path):
    # an ellipsoid has no stable facets -> fallback yields a (smooth) mesh, no crash
    out = generate_ellipsoid_scan(str(tmp_path / "ell"), rx=4, ry=4, rz=5,
                                  n_views=60, mm_per_px=0.05, width=400, height=400)
    p = ReconstructionParams(method="facet", facet_fallback=True)
    mesh = reconstruct_dataset(out, p)
    assert mesh.vertices.shape[0] > 0     # produced something instead of raising
```

- [ ] **Step 2: Run test to verify it fails**

Run: `pytest tests/reconstruction/test_pipeline_facet.py -v`
Expected: FAIL — `TypeError`/`AttributeError` on unknown `method="facet"` fields, or the second test raises `ValueError`.

- [ ] **Step 3: Write minimal implementation**

The `facet_*` params were added in Task 6 Step 1a; this task only adds dispatch.

```python
# gemscanner/reconstruction/pipeline.py — replace the body of reconstruct_dataset
def reconstruct_dataset(dataset_path, params=None):
    dataset = load_dataset(dataset_path)
    params = params if params is not None else ReconstructionParams()
    if params.method == "facet":
        from gemscanner.reconstruction.facet_fit import FacetReconstructor
        try:
            return FacetReconstructor().reconstruct(dataset, params)
        except Exception as exc:
            if not params.facet_fallback:
                raise
            # facet is the highest-quality tier; degrade to the smooth
            # metrology method (soft_hull), and never fail silently so a real
            # regression (or a non-faceted stone) is visible, not masked.
            warnings.warn(f"facet reconstruction failed ({exc}); falling back "
                          "to soft_hull", RuntimeWarning)
            from gemscanner.reconstruction.soft_hull import SoftHullReconstructor
            return SoftHullReconstructor().reconstruct(dataset, params)
    if params.method == "soft_hull":
        from gemscanner.reconstruction.soft_hull import SoftHullReconstructor
        return SoftHullReconstructor().reconstruct(dataset, params)
    return StripIntersectionReconstructor().reconstruct(dataset, params)
```

- [ ] **Step 4: Run test to verify it passes**

Run: `pytest tests/reconstruction/test_pipeline_facet.py -v && pytest -q`
Expected: PASS (both new tests, and the full suite stays green).

- [ ] **Step 5: Commit**

```bash
git add gemscanner/reconstruction/base.py gemscanner/reconstruction/pipeline.py tests/reconstruction/test_pipeline_facet.py
git commit -m "feat(reconstruction): wire method=facet into pipeline with fallback"
```

---

### Task 8: GUI picker entry

Add "Faceted gem (planar)" to the reconstruction panel so a user can select the method when scanning a faceted stone.

**Files:**
- Modify: `gemscanner/gui/reconstruction_panel.py:12-21` (append to `CHOICES`)
- Test: `tests/gui/test_reconstruction_panel.py` (create or append if it exists)

**Interfaces:**
- Consumes: existing `ReconstructionPanel` pattern.
- Produces: a 5th choice mapping to `{"method": "facet", "edge_median_rows": 0, "axial_median_rows": 0}`.

- [ ] **Step 1: Write the failing test**

```python
# tests/gui/test_reconstruction_panel.py  (append; create with this import guard if new)
import pytest
pytest.importorskip("PySide6")
from PySide6.QtWidgets import QApplication
from gemscanner.gui.reconstruction_panel import ReconstructionPanel

def _app():
    return QApplication.instance() or QApplication([])

def test_faceted_choice_present_and_maps_to_facet_method():
    _app()
    panel = ReconstructionPanel()
    labels = [c[0] for c in ReconstructionPanel.CHOICES]
    assert "Faceted gem (planar)" in labels
    idx = labels.index("Faceted gem (planar)")
    panel.set_index(idx)
    assert panel.selected_kwargs()["method"] == "facet"
```

- [ ] **Step 2: Run test to verify it fails**

Run: `pytest tests/gui/test_reconstruction_panel.py -v`
Expected: FAIL — `"Faceted gem (planar)" not in labels`.

- [ ] **Step 3: Write minimal implementation**

```python
# gemscanner/gui/reconstruction_panel.py — append inside the CHOICES list
        ("Faceted gem (planar)",
         {"method": "facet", "edge_median_rows": 0, "axial_median_rows": 0}),
```

- [ ] **Step 4: Run test to verify it passes**

Run: `pytest tests/gui/test_reconstruction_panel.py -v`
Expected: PASS.

- [ ] **Step 5: Commit**

```bash
git add gemscanner/gui/reconstruction_panel.py tests/gui/test_reconstruction_panel.py
git commit -m "feat(gui): add 'Faceted gem (planar)' reconstruction choice"
```

---

### Task 9: gem04 validation (real-scan verification)

Prove the method on the real faceted scan and record the numbers the design promised: per-facet planarity, sharp edges, watertightness, dimensions vs the existing `gem.stl`. This task delivers a runnable script and a short results note — no product code.

**Files:**
- Create: `scripts/validate_facet_gem04.py`
- Create: `docs/superpowers/notes/2026-07-11-facet-gem04-results.md`

**Interfaces:**
- Consumes: `pipeline.reconstruct_dataset`, `storage.mesh_io` (existing STL loader — confirm function name in `gemscanner/storage/mesh_io.py`), `trimesh`.
- Produces: printed metrics + a written results note.

- [ ] **Step 1: Write the validation script**

```python
# scripts/validate_facet_gem04.py
"""Reconstruct scans/gem04 with method=facet and report facet-quality metrics."""
import numpy as np, trimesh
from gemscanner.reconstruction.base import ReconstructionParams
from gemscanner.reconstruction.pipeline import reconstruct_dataset

SCAN = "scans/gem04"

def main():
    mesh = reconstruct_dataset(SCAN, ReconstructionParams(method="facet"))
    fac = mesh.metadata.get("facets", {})
    planes = fac.get("planes", [])
    print(f"facets={len(planes)}  vertices(meet-points)={len(fac.get('vertices', []))}"
          f"  edges={len(fac.get('edges', []))}")
    print(f"watertight={mesh.is_watertight}  volume={mesh.volume:.2f} mm^3")
    ext = mesh.bounding_box.extents
    print(f"extents (mm): {ext[0]:.3f} x {ext[1]:.3f} x {ext[2]:.3f}")
    # planarity: max distance of assigned hull vertices to each plane (um)
    V = np.asarray(mesh.vertices)
    worst = 0.0
    for (a, b, c, d) in planes:
        dist = np.abs(V @ np.array([a, b, c]) - d)
        worst = max(worst, 1000.0 * dist[dist < 0.02].max() if (dist < 0.02).any() else 0)
    print(f"worst on-facet planarity residual: {worst:.1f} um")
    try:
        ref = trimesh.load(f"{SCAN}/gem.stl")
        print(f"reference gem.stl extents (mm): {ref.bounding_box.extents}")
    except Exception as e:
        print(f"(no reference comparison: {e})")
    mesh.export("scans/gem04/gem_facet.stl")
    print("wrote scans/gem04/gem_facet.stl")

if __name__ == "__main__":
    main()
```

- [ ] **Step 2: Run the script**

Run: `python scripts/validate_facet_gem04.py`
Expected: prints facet count, watertight=True, extents matching `gem.stl` to within a few tens of µm, and a planarity residual far below the ~68 µm terracing baseline recorded in the striation notes.

- [ ] **Step 3: Record results**

Write `docs/superpowers/notes/2026-07-11-facet-gem04-results.md` with the printed numbers, a one-line verdict (does it beat the terracing baseline and stay dimensionally faithful?), and any threshold tuning applied (`facet_merge_deg`, `facet_min_inliers`). If facets are over/under-segmented, note the adjusted params.

- [ ] **Step 4: Commit**

```bash
git add scripts/validate_facet_gem04.py docs/superpowers/notes/2026-07-11-facet-gem04-results.md
git commit -m "test(reconstruction): validate faceted method on gem04 real scan"
```

---

## Self-Review

**Spec coverage:**
- §2/§2.1 support-function insight → Tasks 3, 4. ✓
- §4.1 support sampling → Task 3. ✓
- §4.2 Gauss-sphere seed → Task 5. ✓
- §4.3 refit + azimuth refine + merge → Task 6 (`recover_planes`, `_merge_planes`). ✓
- §4.4 table/culet extremal planes → Task 6 (`recover_planes` extremal branch). ✓
- §4.5 half-space assembly, edges, meet-points → Task 6 (`planes_to_polytope`). ✓
- §4.6 fallback → Task 7. ✓
- §5 data structures → Task 6 `mesh.metadata["facets"]` (planes/vertices/edges). Note: the spec's richer `FacetModel` (inter-facet angles, symmetry order) is deferred to metadata basics; angle/symmetry tables are optional gemology extras, flagged in §10 open items, not required for artifact-free geometry. ✓ (scoped)
- §6 params + pipeline + GUI → Tasks 7, 8. ✓
- §7 synthetic GT + gem04 validation → Tasks 1, 2, 9. ✓
- §9a build order → Tasks ordered synthetic-GT-first. ✓

**Placeholder scan:** No TBD/TODO; every code step has concrete code; commands have expected output. ✓

**Type consistency:** `plane` tuples are `(a,b,c,d)` everywhere; `plane_from_affine` returns that; `recover_planes`/`_merge_planes`/`planes_to_polytope` all consume `p["plane"]` as `(a,b,c,d)`; `seed_facets` dict keys (`normal/azimuth/tilt/area`) match `recover_planes` usage; `support_maps` fields (`z/theta/h_right/h_left/valid`) match Task 4/6 usage. ✓

**Ordering check:** `facet_*` params are added in Task 6 Step 1a (where first used); Task 7 only adds pipeline dispatch. No forward dependency remains. ✓

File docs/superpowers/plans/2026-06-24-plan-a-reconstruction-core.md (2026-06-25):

# Plan A — Reconstruction + Vision Core Implementation Plan

> **For agentic workers:** REQUIRED SUB-SKILL: Use superpowers:subagent-driven-development (recommended) or superpowers:executing-plans to implement this plan task-by-task. Steps use checkbox (`- [ ]`) syntax for tracking.

**Goal:** Build the pure-Python heart of the gemstone scanner — silhouette extraction plus Approach-A (per-slice strip-intersection) visual-hull reconstruction with mesh export — validated end-to-end against synthetic silhouette stacks, with zero hardware.

**Architecture:** A telecentric lens gives an orthographic projection, so each image row is a fixed object height and each silhouette is a parallel "slab" in the object's rotating frame. For every row, we intersect the back-projected slabs from all rotation angles (convex-polygon clipping) to get a cross-section, then loft the stack of cross-sections into a watertight mesh. Reconstruction reads only a stored dataset (frames + `manifest.json`), so it is fully decoupled from capture and re-runnable offline. A synthetic ellipsoid generator produces ground-truth datasets for testing.

**Tech Stack:** Python 3.11+, NumPy, OpenCV (`opencv-python`), trimesh, pytest. (Open3D viewer and live UI are Plan C, not here.)

> **Post-execution corrections (2026-06-24).** This plan was executed and merged. Three deltas from the code blocks below were applied during execution and are the source of truth: (1) `coords.row_to_z`/`z_to_row` use a **center-of-image** z-origin (`z=0` at row `(height-1)/2`), not the bottom-row origin shown in Task 2 — required so the reconstructor's z matches the generator's and the Task 10 midplane test straddles the equator; the snippet in Task 2 has been updated to match. (2) `mesh.py` calls `fix_normals(multibody=False)` to avoid pulling in scipy (Task 11). (3) `pytest` moved to `[project.optional-dependencies] dev`, the empty-input guard in `clip_convex_polygon` returns a canonical `(0,2)`, `_largest_component` returns a copy, the cap centers use `polygon_centroid`, and `params or …` became `params is not None`. Do not "revert" these when reading the older snippets below.

## Global Constraints

- Python **3.11+**; Windows host.
- Dependencies limited to: `numpy`, `opencv-python`, `trimesh`, `pytest`. No Open3D, no Shapely in Plan A.
- Reconstruction reads **only** a dataset folder (`frames/*.png` + `manifest.json`); it never talks to hardware.
- **Frames are registered to the calibrated rotation axis, never re-centered** (off-center support depends on this).
- Backlit convention: **object is dark, background is bright** (silhouette = dark pixels).
- Horizontal pixel↔mm and row↔height mappings live in **one** module (`gemscanner/coords.py`) and are shared by the generator and the reconstructor — never duplicated.
- All geometry in millimeters in the object (gem-fixed) frame.
- Package import root is `gemscanner`; tests live under `tests/` mirroring the package.

---

### Task 1: Project scaffold

**Files:**
- Create: `pyproject.toml`
- Create: `gemscanner/__init__.py`
- Test: `tests/test_smoke.py`

**Interfaces:**
- Consumes: nothing.
- Produces: importable `gemscanner` package; `pytest` runnable.

- [ ] **Step 1: Write the failing test**

```python
# tests/test_smoke.py
def test_package_imports():
    import gemscanner
    assert gemscanner.__version__ == "0.1.0"
```

- [ ] **Step 2: Run test to verify it fails**

Run: `pytest tests/test_smoke.py -v`
Expected: FAIL (`ModuleNotFoundError: No module named 'gemscanner'`)

- [ ] **Step 3: Create the package and config**

```toml
# pyproject.toml
[build-system]
requires = ["setuptools>=68"]
build-backend = "setuptools.build_meta"

[project]
name = "gemscanner"
version = "0.1.0"
requires-python = ">=3.11"
dependencies = ["numpy", "opencv-python", "trimesh", "pytest"]

[tool.setuptools.packages.find]
include = ["gemscanner*"]

[tool.pytest.ini_options]
testpaths = ["tests"]
```

```python
# gemscanner/__init__.py
__version__ = "0.1.0"
```

- [ ] **Step 4: Install and run the test to verify it passes**

Run: `pip install -e . && pytest tests/test_smoke.py -v`
Expected: PASS

- [ ] **Step 5: Commit**

```bash
git init
git add pyproject.toml gemscanner/__init__.py tests/test_smoke.py
git commit -m "chore: scaffold gemscanner package"
```

---

### Task 2: Coordinate mappings (`coords.py`)

**Files:**
- Create: `gemscanner/coords.py`
- Test: `tests/test_coords.py`

**Interfaces:**
- Consumes: nothing.
- Produces:
  - `row_to_z(v: float, height: int, mm_per_px: float) -> float`
  - `z_to_row(z: float, height: int, mm_per_px: float) -> float`
  - `axis_column_at_row(axis_column: float, axis_tilt_rad: float, v: float, height: int) -> float`
  - `projection_to_column(p_mm: float, axis_col: float, mm_per_px: float) -> float`
  - `column_to_projection(u: float, axis_col: float, mm_per_px: float) -> float`

- [ ] **Step 1: Write the failing test**

```python
# tests/test_coords.py
import math
from gemscanner.coords import (
    row_to_z, z_to_row, axis_column_at_row,
    projection_to_column, column_to_projection,
)

def test_row_z_roundtrip():
    z = row_to_z(120, height=400, mm_per_px=0.05)
    assert math.isclose(z_to_row(z, 400, 0.05), 120, abs_tol=1e-9)

def test_projection_roundtrip():
    u = projection_to_column(1.3, axis_col=199.5, mm_per_px=0.05)
    assert math.isclose(column_to_projection(u, 199.5, 0.05), 1.3, abs_tol=1e-9)

def test_axis_tilt_shifts_columns():
    # zero tilt => constant axis column
    assert axis_column_at_row(199.5, 0.0, v=0, height=400) == 199.5
    # positive tilt => columns shift linearly around vertical center
    v0 = (400 - 1) / 2
    expected = 199.5 + math.tan(0.01) * (10 - v0)
    assert math.isclose(axis_column_at_row(199.5, 0.01, 10, 400), expected, abs_tol=1e-9)
```

- [ ] **Step 2: Run test to verify it fails**

Run: `pytest tests/test_coords.py -v`
Expected: FAIL (`ModuleNotFoundError: gemscanner.coords`)

- [ ] **Step 3: Write the implementation**

```python
# gemscanner/coords.py
import math

def row_to_z(v, height, mm_per_px):
    """Map image row v (0 at top) to object height z in mm (increasing upward).
    z=0 at the vertical centre of the image (row (height-1)/2)."""
    return ((height - 1) / 2.0 - v) * mm_per_px

def z_to_row(z, height, mm_per_px):
    return (height - 1) / 2.0 - z / mm_per_px

def axis_column_at_row(axis_column, axis_tilt_rad, v, height):
    """Rotation-axis pixel column at row v, accounting for small axis tilt."""
    v0 = (height - 1) / 2.0
    return axis_column + math.tan(axis_tilt_rad) * (v - v0)

def projection_to_column(p_mm, axis_col, mm_per_px):
    """Horizontal object coordinate (mm, relative to axis) -> pixel column."""
    return axis_col + p_mm / mm_per_px

def column_to_projection(u, axis_col, mm_per_px):
    """Pixel column -> horizontal object coordinate (mm, relative to axis)."""
    return (u - axis_col) * mm_per_px
```

- [ ] **Step 4: Run test to verify it passes**

Run: `pytest tests/test_coords.py -v`
Expected: PASS

- [ ] **Step 5: Commit**

```bash
git add gemscanner/coords.py tests/test_coords.py
git commit -m "feat: coordinate mappings between pixels, height, and object mm"
```

---

### Task 3: Convex polygon half-plane clipping (`geometry/halfplane.py`)

**Files:**
- Create: `gemscanner/geometry/__init__.py`
- Create: `gemscanner/geometry/halfplane.py`
- Test: `tests/geometry/test_halfplane.py`

**Interfaces:**
- Consumes: nothing.
- Produces: `clip_convex_polygon(polygon: np.ndarray, normal, offset: float) -> np.ndarray`
  keeps the region where `dot(normal, point) <= offset`; returns an `(M,2)` float array, or an empty `(0,2)` array if fully clipped.

- [ ] **Step 1: Write the failing test**

```python
# tests/geometry/test_halfplane.py
import numpy as np
from gemscanner.geometry.halfplane import clip_convex_polygon

SQUARE = np.array([[-1, -1], [1, -1], [1, 1], [-1, 1]], dtype=float)

def test_clip_keeps_left_half():
    # keep x <= 0  => normal (1,0), offset 0
    out = clip_convex_polygon(SQUARE, [1.0, 0.0], 0.0)
    assert out[:, 0].max() <= 1e-9
    assert np.isclose(out[:, 0].min(), -1.0)

def test_clip_empty_when_fully_outside():
    out = clip_convex_polygon(SQUARE, [1.0, 0.0], -5.0)
    assert out.shape == (0, 2)

def test_clip_noop_when_fully_inside():
    out = clip_convex_polygon(SQUARE, [1.0, 0.0], 5.0)
    assert len(out) == 4
```

- [ ] **Step 2: Run test to verify it fails**

Run: `pytest tests/geometry/test_halfplane.py -v`
Expected: FAIL (`ModuleNotFoundError: gemscanner.geometry.halfplane`)

- [ ] **Step 3: Write the implementation**

```python
# gemscanner/geometry/__init__.py
```

```python
# gemscanner/geometry/halfplane.py
import numpy as np

def clip_convex_polygon(polygon, normal, offset):
    """Sutherland-Hodgman clip of a convex polygon by a single half-plane.

    Keeps the region where dot(normal, point) <= offset.
    Returns an (M,2) float array, or an empty (0,2) array if fully clipped.
    """
    polygon = np.asarray(polygon, dtype=float)
    if len(polygon) == 0:
        return polygon
    normal = np.asarray(normal, dtype=float)
    result = []
    n = len(polygon)
    for i in range(n):
        cur = polygon[i]
        nxt = polygon[(i + 1) % n]
        cur_in = np.dot(normal, cur) <= offset
        nxt_in = np.dot(normal, nxt) <= offset
        if cur_in:
            result.append(cur)
        if cur_in != nxt_in:
            d = np.dot(normal, nxt - cur)
            if abs(d) > 1e-12:
                t = (offset - np.dot(normal, cur)) / d
                result.append(cur + t * (nxt - cur))
    if not result:
        return np.empty((0, 2), dtype=float)
    return np.array(result, dtype=float)
```

- [ ] **Step 4: Run test to verify it passes**

Run: `pytest tests/geometry/test_halfplane.py -v`
Expected: PASS

- [ ] **Step 5: Commit**

```bash
git add gemscanner/geometry/__init__.py gemscanner/geometry/halfplane.py tests/geometry/test_halfplane.py
git commit -m "feat: convex polygon half-plane clipping"
```

---

### Task 4: Polygon helpers (`geometry/polygon.py`)

**Files:**
- Create: `gemscanner/geometry/polygon.py`
- Test: `tests/geometry/test_polygon.py`

**Interfaces:**
- Consumes: nothing.
- Produces:
  - `polygon_area(polygon: np.ndarray) -> float`
  - `polygon_centroid(polygon: np.ndarray) -> np.ndarray` (shape `(2,)`, interior for convex polygons)
  - `ray_radius(polygon: np.ndarray, center, angle: float) -> float` — distance from an interior `center` to the boundary along direction `(cos angle, sin angle)`; returns `0.0` if no forward hit.

- [ ] **Step 1: Write the failing test**

```python
# tests/geometry/test_polygon.py
import math
import numpy as np
from gemscanner.geometry.polygon import polygon_area, polygon_centroid, ray_radius

SQUARE = np.array([[-2, -2], [2, -2], [2, 2], [-2, 2]], dtype=float)

def test_area():
    assert math.isclose(polygon_area(SQUARE), 16.0, abs_tol=1e-9)

def test_centroid():
    c = polygon_centroid(SQUARE)
    assert np.allclose(c, [0.0, 0.0], atol=1e-9)

def test_ray_radius_hits_right_edge():
    r = ray_radius(SQUARE, [0.0, 0.0], 0.0)   # +x direction
    assert math.isclose(r, 2.0, abs_tol=1e-9)

def test_ray_radius_diagonal():
    r = ray_radius(SQUARE, [0.0, 0.0], math.radians(45))
    assert math.isclose(r, 2.0 * math.sqrt(2), abs_tol=1e-6)
```

- [ ] **Step 2: Run test to verify it fails**

Run: `pytest tests/geometry/test_polygon.py -v`
Expected: FAIL (`ModuleNotFoundError: gemscanner.geometry.polygon`)

- [ ] **Step 3: Write the implementation**

```python
# gemscanner/geometry/polygon.py
import numpy as np

def polygon_area(polygon):
    x = polygon[:, 0]
    y = polygon[:, 1]
    return 0.5 * abs(np.dot(x, np.roll(y, -1)) - np.dot(y, np.roll(x, -1)))

def polygon_centroid(polygon):
    x = polygon[:, 0]
    y = polygon[:, 1]
    x1 = np.roll(x, -1)
    y1 = np.roll(y, -1)
    cross = x * y1 - x1 * y
    a = cross.sum() / 2.0
    if abs(a) < 1e-12:
        return polygon.mean(axis=0)
    cx = ((x + x1) * cross).sum() / (6 * a)
    cy = ((y + y1) * cross).sum() / (6 * a)
    return np.array([cx, cy])

def ray_radius(polygon, center, angle):
    """Distance from interior `center` to the boundary along (cos, sin)."""
    d = np.array([np.cos(angle), np.sin(angle)])
    center = np.asarray(center, dtype=float)
    n = len(polygon)
    best = None
    for i in range(n):
        a = polygon[i]
        b = polygon[(i + 1) % n]
        e = b - a
        # solve center + t*d = a + s*e  =>  [d | -e] [t, s]^T = a - center
        denom = d[0] * (-e[1]) - d[1] * (-e[0])
        if abs(denom) < 1e-12:
            continue
        diff = a - center
        t = (diff[0] * (-e[1]) - diff[1] * (-e[0])) / denom
        s = (d[0] * diff[1] - d[1] * diff[0]) / denom
        if t >= -1e-9 and -1e-9 <= s <= 1 + 1e-9:
            if best is None or t < best:
                best = t
    return float(best) if best is not None else 0.0
```

- [ ] **Step 4: Run test to verify it passes**

Run: `pytest tests/geometry/test_polygon.py -v`
Expected: PASS

- [ ] **Step 5: Commit**

```bash
git add gemscanner/geometry/polygon.py tests/geometry/test_polygon.py
git commit -m "feat: polygon area, centroid, and interior ray-radius helpers"
```

---

### Task 5: Scan manifest (`storage/manifest.py`)

**Files:**
- Create: `gemscanner/storage/__init__.py`
- Create: `gemscanner/storage/manifest.py`
- Test: `tests/storage/test_manifest.py`

**Interfaces:**
- Consumes: nothing.
- Produces: `ScanManifest` dataclass with fields
  `angles_deg: list[float]`, `mm_per_px: float`, `axis_column: float`,
  `axis_tilt_rad: float = 0.0`, `eccentricity_mm: float | None = None`,
  `image_width: int = 0`, `image_height: int = 0`,
  `frame_files: list[str] = []`, `metadata: dict = {}`;
  methods `save(path)` and classmethod `load(path)`.

- [ ] **Step 1: Write the failing test**

```python
# tests/storage/test_manifest.py
from gemscanner.storage.manifest import ScanManifest

def test_manifest_roundtrip(tmp_path):
    m = ScanManifest(
        angles_deg=[0.0, 2.0, 4.0], mm_per_px=0.05, axis_column=199.5,
        image_width=400, image_height=400, frame_files=["frames/0000.png"],
        metadata={"shape": "ellipsoid"},
    )
    p = tmp_path / "manifest.json"
    m.save(p)
    loaded = ScanManifest.load(p)
    assert loaded.angles_deg == [0.0, 2.0, 4.0]
    assert loaded.mm_per_px == 0.05
    assert loaded.metadata["shape"] == "ellipsoid"
    assert loaded.axis_tilt_rad == 0.0
```

- [ ] **Step 2: Run test to verify it fails**

Run: `pytest tests/storage/test_manifest.py -v`
Expected: FAIL (`ModuleNotFoundError: gemscanner.storage.manifest`)

- [ ] **Step 3: Write the implementation**

```python
# gemscanner/storage/__init__.py
```

```python
# gemscanner/storage/manifest.py
from dataclasses import dataclass, field, asdict
import json

@dataclass
class ScanManifest:
    angles_deg: list
    mm_per_px: float
    axis_column: float
    axis_tilt_rad: float = 0.0
    eccentricity_mm: float = None
    image_width: int = 0
    image_height: int = 0
    frame_files: list = field(default_factory=list)
    metadata: dict = field(default_factory=dict)

    def save(self, path):
        with open(path, "w", encoding="utf-8") as f:
            json.dump(asdict(self), f, indent=2)

    @classmethod
    def load(cls, path):
        with open(path, encoding="utf-8") as f:
            data = json.load(f)
        return cls(**data)
```

- [ ] **Step 4: Run test to verify it passes**

Run: `pytest tests/storage/test_manifest.py -v`
Expected: PASS

- [ ] **Step 5: Commit**

```bash
git add gemscanner/storage/__init__.py gemscanner/storage/manifest.py tests/storage/test_manifest.py
git commit -m "feat: ScanManifest load/save"
```

---

### Task 6: Synthetic ellipsoid scan generator (`synthetic/generator.py`)

**Files:**
- Create: `gemscanner/synthetic/__init__.py`
- Create: `gemscanner/synthetic/generator.py`
- Test: `tests/synthetic/test_generator.py`

**Interfaces:**
- Consumes: `coords.projection_to_column`, `storage.manifest.ScanManifest`.
- Produces: `generate_ellipsoid_scan(out_dir, rx, ry, rz, n_views=180, mm_per_px=0.05, width=400, height=400, center_offset=(0.0, 0.0)) -> str` (returns `out_dir`). Writes `out_dir/frames/NNNN.png` (dark ellipsoid silhouette on bright background) and `out_dir/manifest.json`. Ground-truth `rx, ry, rz, center_offset` are stored in `manifest.metadata`.

- [ ] **Step 1: Write the failing test**

```python
# tests/synthetic/test_generator.py
import os
import numpy as np
import cv2
from gemscanner.synthetic.generator import generate_ellipsoid_scan
from gemscanner.storage.manifest import ScanManifest

def test_generates_frames_and_manifest(tmp_path):
    out = generate_ellipsoid_scan(str(tmp_path / "scan"), rx=4, ry=3, rz=5,
                                  n_views=18, mm_per_px=0.05, width=400, height=400)
    m = ScanManifest.load(os.path.join(out, "manifest.json"))
    assert len(m.frame_files) == 18
    assert m.metadata["rx"] == 4
    img = cv2.imread(os.path.join(out, m.frame_files[0]), cv2.IMREAD_GRAYSCALE)
    assert img.shape == (400, 400)
    # silhouette is dark on bright background: both extremes present
    assert img.min() == 0 and img.max() == 255

def test_widest_view_matches_major_axis(tmp_path):
    out = generate_ellipsoid_scan(str(tmp_path / "scan"), rx=5, ry=2, rz=5,
                                  n_views=4, mm_per_px=0.05, width=400, height=400)
    m = ScanManifest.load(os.path.join(out, "manifest.json"))
    img = cv2.imread(os.path.join(out, m.frame_files[0]), cv2.IMREAD_GRAYSCALE)  # theta=0
    dark_cols = np.where((img == 0).any(axis=0))[0]
    width_px = dark_cols[-1] - dark_cols[0] + 1
    # theta=0 view shows full 2*rx width => 2*5 / 0.05 = 200 px (within rounding)
    assert abs(width_px - 200) <= 2
```

- [ ] **Step 2: Run test to verify it fails**

Run: `pytest tests/synthetic/test_generator.py -v`
Expected: FAIL (`ModuleNotFoundError: gemscanner.synthetic.generator`)

- [ ] **Step 3: Write the implementation**

```python
# gemscanner/synthetic/__init__.py
```

```python
# gemscanner/synthetic/generator.py
import os
import math
import numpy as np
import cv2
from gemscanner.coords import projection_to_column
from gemscanner.storage.manifest import ScanManifest

def generate_ellipsoid_scan(out_dir, rx, ry, rz, n_views=180, mm_per_px=0.05,
                            width=400, height=400, center_offset=(0.0, 0.0)):
    """Render orthographic silhouettes of an ellipsoid rotating about the vertical
    axis. The ellipsoid center sits at object-frame (cx, cy) and rotates with the
    object (eccentric placement). Background is bright (255), silhouette dark (0)."""
    os.makedirs(os.path.join(out_dir, "frames"), exist_ok=True)
    axis_column = (width - 1) / 2.0
    v0 = (height - 1) / 2.0
    cx, cy = center_offset
    angles = [i * 360.0 / n_views for i in range(n_views)]
    frame_files = []
    for i, ang in enumerate(angles):
        th = math.radians(ang)
        img = np.full((height, width), 255, dtype=np.uint8)
        p_c = cx * math.cos(th) - cy * math.sin(th)        # projected center swing
        for v in range(height):
            z = (v0 - v) * mm_per_px
            if abs(z) >= rz:
                continue
            s = math.sqrt(max(0.0, 1.0 - (z / rz) ** 2))
            half = s * math.sqrt((rx * math.cos(th)) ** 2 + (ry * math.sin(th)) ** 2)
            left = projection_to_column(p_c - half, axis_column, mm_per_px)
            right = projection_to_column(p_c + half, axis_column, mm_per_px)
            lo = max(0, int(math.ceil(left)))
            hi = min(width - 1, int(math.floor(right)))
            if hi >= lo:
                img[v, lo:hi + 1] = 0
        fname = f"{i:04d}.png"
        cv2.imwrite(os.path.join(out_dir, "frames", fname), img)
        frame_files.append(f"frames/{fname}")
    manifest = ScanManifest(
        angles_deg=angles, mm_per_px=mm_per_px, axis_column=axis_column,
        axis_tilt_rad=0.0, image_width=width, image_height=height,
        frame_files=frame_files,
        metadata={"shape": "ellipsoid", "rx": rx, "ry": ry, "rz": rz,
                  "center_offset": [cx, cy]},
    )
    manifest.save(os.path.join(out_dir, "manifest.json"))
    return out_dir
```

- [ ] **Step 4: Run test to verify it passes**

Run: `pytest tests/synthetic/test_generator.py -v`
Expected: PASS

- [ ] **Step 5: Commit**

```bash
git add gemscanner/synthetic/__init__.py gemscanner/synthetic/generator.py tests/synthetic/test_generator.py
git commit -m "feat: synthetic ellipsoid silhouette scan generator"
```

---

### Task 7: Silhouette extraction (`vision/silhouette.py`)

**Files:**
- Create: `gemscanner/vision/__init__.py`
- Create: `gemscanner/vision/silhouette.py`
- Test: `tests/vision/test_silhouette.py`

**Interfaces:**
- Consumes: nothing (operates on a grayscale `np.ndarray`).
- Produces:
  - `extract_silhouette(image, threshold=None, holder_mask_rows=0) -> np.ndarray` (bool mask, `True` = object). Backlit convention: object is darker; uses Otsu when `threshold is None`. Keeps only the largest connected component. `holder_mask_rows` forces the bottom N rows to background.
  - `row_spans(mask) -> np.ndarray` shape `(H, 2)` int array of `[left, right]` foreground columns per row; `[-1, -1]` for empty rows.

- [ ] **Step 1: Write the failing test**

```python
# tests/vision/test_silhouette.py
import numpy as np
from gemscanner.vision.silhouette import extract_silhouette, row_spans

def make_image():
    img = np.full((20, 20), 255, dtype=np.uint8)
    img[5:15, 6:14] = 0          # dark rectangle = object
    return img

def test_extract_marks_dark_region():
    mask = extract_silhouette(make_image())
    assert mask[10, 10]            # inside object
    assert not mask[0, 0]          # background

def test_largest_component_drops_specks():
    img = make_image()
    img[1, 1] = 0                  # tiny speck
    mask = extract_silhouette(img)
    assert not mask[1, 1]

def test_row_spans():
    mask = extract_silhouette(make_image())
    spans = row_spans(mask)
    assert tuple(spans[10]) == (6, 13)
    assert tuple(spans[0]) == (-1, -1)

def test_holder_mask_clears_bottom_rows():
    mask = extract_silhouette(make_image(), holder_mask_rows=6)
    assert not mask[14].any()      # row 14 is within bottom 6 rows
```

- [ ] **Step 2: Run test to verify it fails**

Run: `pytest tests/vision/test_silhouette.py -v`
Expected: FAIL (`ModuleNotFoundError: gemscanner.vision.silhouette`)

- [ ] **Step 3: Write the implementation**

```python
# gemscanner/vision/__init__.py
```

```python
# gemscanner/vision/silhouette.py
import numpy as np
import cv2

def extract_silhouette(image, threshold=None, holder_mask_rows=0):
    """Return a bool mask (True = object). Backlit: object is darker than background."""
    if image.ndim == 3:
        image = cv2.cvtColor(image, cv2.COLOR_BGR2GRAY)
    if threshold is None:
        _, binimg = cv2.threshold(image, 0, 255,
                                  cv2.THRESH_BINARY_INV + cv2.THRESH_OTSU)
    else:
        _, binimg = cv2.threshold(image, threshold, 255, cv2.THRESH_BINARY_INV)
    mask = binimg > 0
    if holder_mask_rows > 0:
        mask[-holder_mask_rows:, :] = False
    return _largest_component(mask)

def _largest_component(mask):
    m = mask.astype(np.uint8)
    num, labels, stats, _ = cv2.connectedComponentsWithStats(m, connectivity=8)
    if num <= 1:
        return mask
    areas = stats[1:, cv2.CC_STAT_AREA]
    largest = 1 + int(np.argmax(areas))
    return labels == largest

def row_spans(mask):
    """(H,2) int array of [left, right] foreground columns per row; [-1,-1] if empty."""
    h = mask.shape[0]
    spans = np.full((h, 2), -1, dtype=int)
    for v in range(h):
        cols = np.where(mask[v])[0]
        if cols.size:
            spans[v] = (cols[0], cols[-1])
    return spans
```

- [ ] **Step 4: Run test to verify it passes**

Run: `pytest tests/vision/test_silhouette.py -v`
Expected: PASS

- [ ] **Step 5: Commit**

```bash
git add gemscanner/vision/__init__.py gemscanner/vision/silhouette.py tests/vision/test_silhouette.py
git commit -m "feat: silhouette extraction and per-row spans"
```

---

### Task 8: Dataset loader (`storage/dataset.py`)

**Files:**
- Create: `gemscanner/storage/dataset.py`
- Test: `tests/storage/test_dataset.py`

**Interfaces:**
- Consumes: `storage.manifest.ScanManifest`.
- Produces:
  - `ScanDataset` with `.path`, `.manifest`, `frame_count() -> int`, `load_frame(i) -> np.ndarray` (grayscale), `iter_frames() -> Iterator[tuple[float, np.ndarray]]` yielding `(angle_deg, image)`.
  - `load_dataset(path) -> ScanDataset`.

- [ ] **Step 1: Write the failing test**

```python
# tests/storage/test_dataset.py
from gemscanner.synthetic.generator import generate_ellipsoid_scan
from gemscanner.storage.dataset import load_dataset

def test_load_and_iterate(tmp_path):
    out = generate_ellipsoid_scan(str(tmp_path / "scan"), rx=4, ry=3, rz=5,
                                  n_views=6, mm_per_px=0.05, width=200, height=200)
    ds = load_dataset(out)
    assert ds.frame_count() == 6
    frames = list(ds.iter_frames())
    assert len(frames) == 6
    angle, img = frames[0]
    assert angle == 0.0
    assert img.shape == (200, 200)
```

- [ ] **Step 2: Run test to verify it fails**

Run: `pytest tests/storage/test_dataset.py -v`
Expected: FAIL (`ModuleNotFoundError: gemscanner.storage.dataset`)

- [ ] **Step 3: Write the implementation**

```python
# gemscanner/storage/dataset.py
import os
import cv2
from gemscanner.storage.manifest import ScanManifest

class ScanDataset:
    def __init__(self, path, manifest):
        self.path = path
        self.manifest = manifest

    def frame_count(self):
        return len(self.manifest.frame_files)

    def load_frame(self, i):
        full = os.path.join(self.path, self.manifest.frame_files[i])
        img = cv2.imread(full, cv2.IMREAD_GRAYSCALE)
        if img is None:
            raise FileNotFoundError(full)
        return img

    def iter_frames(self):
        for i in range(self.frame_count()):
            yield self.manifest.angles_deg[i], self.load_frame(i)

def load_dataset(path):
    manifest = ScanManifest.load(os.path.join(path, "manifest.json"))
    return ScanDataset(path, manifest)
```

- [ ] **Step 4: Run test to verify it passes**

Run: `pytest tests/storage/test_dataset.py -v`
Expected: PASS

- [ ] **Step 5: Commit**

```bash
git add gemscanner/storage/dataset.py tests/storage/test_dataset.py
git commit -m "feat: scan dataset loader"
```

---

### Task 9: Reconstruction params & slice dataclasses (`reconstruction/base.py`)

**Files:**
- Create: `gemscanner/reconstruction/__init__.py`
- Create: `gemscanner/reconstruction/base.py`
- Test: `tests/reconstruction/test_base.py`

**Interfaces:**
- Consumes: nothing.
- Produces:
  - `ReconstructionParams` dataclass: `n_radial: int = 180`, `holder_mask_rows: int = 0`, `threshold: int | None = None`, `bbox_mm: float = 50.0`.
  - `SliceResult` dataclass: `z_mm: float`, `polygon: np.ndarray | None = None`.

- [ ] **Step 1: Write the failing test**

```python
# tests/reconstruction/test_base.py
from gemscanner.reconstruction.base import ReconstructionParams, SliceResult

def test_defaults():
    p = ReconstructionParams()
    assert p.n_radial == 180
    assert p.bbox_mm == 50.0
    s = SliceResult(z_mm=1.5)
    assert s.z_mm == 1.5
    assert s.polygon is None
```

- [ ] **Step 2: Run test to verify it fails**

Run: `pytest tests/reconstruction/test_base.py -v`
Expected: FAIL (`ModuleNotFoundError: gemscanner.reconstruction.base`)

- [ ] **Step 3: Write the implementation**

```python
# gemscanner/reconstruction/__init__.py
```

```python
# gemscanner/reconstruction/base.py
from dataclasses import dataclass

@dataclass
class ReconstructionParams:
    n_radial: int = 180
    holder_mask_rows: int = 0
    threshold: int = None
    bbox_mm: float = 50.0

@dataclass
class SliceResult:
    z_mm: float
    polygon: object = None     # np.ndarray (N,2) in object-frame mm, or None
```

- [ ] **Step 4: Run test to verify it passes**

Run: `pytest tests/reconstruction/test_base.py -v`
Expected: PASS

- [ ] **Step 5: Commit**

```bash
git add gemscanner/reconstruction/__init__.py gemscanner/reconstruction/base.py tests/reconstruction/test_base.py
git commit -m "feat: reconstruction params and slice result types"
```

---

### Task 10: Strip-intersection cross-sections (`reconstruction/strip_intersection.py`)

**Files:**
- Create: `gemscanner/reconstruction/strip_intersection.py`
- Test: `tests/reconstruction/test_strip_intersection.py`

**Interfaces:**
- Consumes: `coords.{row_to_z, axis_column_at_row, column_to_projection}`, `vision.silhouette.{extract_silhouette, row_spans}`, `geometry.halfplane.clip_convex_polygon`, `reconstruction.base.{ReconstructionParams, SliceResult}`, `storage.dataset.ScanDataset`.
- Produces:
  - `StripIntersectionReconstructor` with
    `slice_cross_sections(dataset, params=None) -> list[SliceResult]` and
    `reconstruct(dataset, params=None) -> trimesh.Trimesh` (delegates to `mesh.loft_slices_to_mesh`, built in Task 11).

**Math:** For frame `i` at angle θ, the slab normal is `n = (cos θ, -sin θ)`. A foreground span `[L, R]` at row `v` maps to object-frame projection bounds `pmin = column_to_projection(L, axis_col_v)`, `pmax = column_to_projection(R, axis_col_v)`. The cross-section is `{p : pmin_i ≤ n_i·p ≤ pmax_i for all i}` — start from a `bbox_mm` square and clip by each pair of half-planes. If **any** frame has no foreground at row `v`, the object does not reach that height → the slice is empty.

- [ ] **Step 1: Write the failing test**

```python
# tests/reconstruction/test_strip_intersection.py
import numpy as np
from gemscanner.synthetic.generator import generate_ellipsoid_scan
from gemscanner.storage.dataset import load_dataset
from gemscanner.reconstruction.strip_intersection import StripIntersectionReconstructor
from gemscanner.geometry.polygon import polygon_area

def test_midplane_cross_section_matches_ellipse_area(tmp_path):
    out = generate_ellipsoid_scan(str(tmp_path / "scan"), rx=4, ry=3, rz=5,
                                  n_views=180, mm_per_px=0.05, width=400, height=400)
    ds = load_dataset(out)
    slices = StripIntersectionReconstructor().slice_cross_sections(ds)
    # mid-height slice (z ~ 0) should approximate the equatorial ellipse pi*rx*ry
    mids = [s for s in slices if s.polygon is not None and abs(s.z_mm) < 0.05]
    assert mids, "expected a near-equatorial non-empty slice"
    area = polygon_area(mids[0].polygon)
    assert abs(area - np.pi * 4 * 3) < 1.0     # within 1 mm^2

def test_slices_empty_above_top(tmp_path):
    out = generate_ellipsoid_scan(str(tmp_path / "scan"), rx=4, ry=3, rz=5,
                                  n_views=60, mm_per_px=0.05, width=400, height=400)
    ds = load_dataset(out)
    slices = StripIntersectionReconstructor().slice_cross_sections(ds)
    tops = [s for s in slices if s.z_mm > 5.2]
    assert all(s.polygon is None for s in tops)
```

- [ ] **Step 2: Run test to verify it fails**

Run: `pytest tests/reconstruction/test_strip_intersection.py -v`
Expected: FAIL (`ModuleNotFoundError: gemscanner.reconstruction.strip_intersection`)

- [ ] **Step 3: Write the implementation**

```python
# gemscanner/reconstruction/strip_intersection.py
import math
import numpy as np
from gemscanner.coords import row_to_z, axis_column_at_row, column_to_projection
from gemscanner.vision.silhouette import extract_silhouette, row_spans
from gemscanner.geometry.halfplane import clip_convex_polygon
from gemscanner.reconstruction.base import ReconstructionParams, SliceResult

class StripIntersectionReconstructor:
    def slice_cross_sections(self, dataset, params=None):
        params = params or ReconstructionParams()
        m = dataset.manifest
        H = m.image_height
        mmpp = m.mm_per_px

        frames = []
        for i in range(dataset.frame_count()):
            img = dataset.load_frame(i)
            mask = extract_silhouette(img, params.threshold, params.holder_mask_rows)
            spans = row_spans(mask)
            th = math.radians(m.angles_deg[i])
            normal = np.array([math.cos(th), -math.sin(th)])
            frames.append((spans, normal))

        slices = []
        for v in range(H):
            z = row_to_z(v, H, mmpp)
            axis_col = axis_column_at_row(m.axis_column, m.axis_tilt_rad, v, H)
            b = params.bbox_mm
            poly = np.array([[-b, -b], [b, -b], [b, b], [-b, b]], dtype=float)
            empty = False
            for spans, normal in frames:
                L, R = spans[v]
                if L < 0:
                    empty = True
                    break
                pmin = column_to_projection(L, axis_col, mmpp)
                pmax = column_to_projection(R, axis_col, mmpp)
                poly = clip_convex_polygon(poly, normal, pmax)
                if len(poly) == 0:
                    empty = True
                    break
                poly = clip_convex_polygon(poly, -normal, -pmin)
                if len(poly) == 0:
                    empty = True
                    break
            if empty or len(poly) < 3:
                slices.append(SliceResult(z, None))
            else:
                slices.append(SliceResult(z, poly))
        return slices

    def reconstruct(self, dataset, params=None):
        from gemscanner.reconstruction.mesh import loft_slices_to_mesh
        params = params or ReconstructionParams()
        slices = self.slice_cross_sections(dataset, params)
        return loft_slices_to_mesh(slices, params.n_radial)
```

- [ ] **Step 4: Run test to verify it passes**

Run: `pytest tests/reconstruction/test_strip_intersection.py -v`
Expected: PASS

- [ ] **Step 5: Commit**

```bash
git add gemscanner/reconstruction/strip_intersection.py tests/reconstruction/test_strip_intersection.py
git commit -m "feat: per-slice strip-intersection cross-sections"
```

---

### Task 11: Loft slices into a mesh (`reconstruction/mesh.py`)

**Files:**
- Create: `gemscanner/reconstruction/mesh.py`
- Test: `tests/reconstruction/test_mesh.py`

**Interfaces:**
- Consumes: `geometry.polygon.{polygon_centroid, polygon_area, ray_radius}`, `reconstruction.base.SliceResult`, `trimesh`.
- Produces: `loft_slices_to_mesh(slices: list[SliceResult], n_radial=180) -> trimesh.Trimesh`. Keeps the largest contiguous run of non-empty slices, radially resamples each slice around its centroid into `n_radial` ring points, connects adjacent rings into side triangles, and caps top and bottom with centroid fans. Raises `ValueError` if fewer than two non-empty slices.

- [ ] **Step 1: Write the failing test**

```python
# tests/reconstruction/test_mesh.py
import numpy as np
import pytest
from gemscanner.reconstruction.base import SliceResult
from gemscanner.reconstruction.mesh import loft_slices_to_mesh

def square(half):
    return np.array([[-half, -half], [half, -half], [half, half], [-half, half]], float)

def test_lofts_watertight_box():
    slices = [SliceResult(z_mm=z, polygon=square(2.0)) for z in (0.0, 1.0, 2.0)]
    mesh = loft_slices_to_mesh(slices, n_radial=64)
    assert mesh.is_watertight
    assert mesh.volume > 0
    ext = mesh.bounding_box.extents
    assert abs(ext[0] - 4.0) < 0.2 and abs(ext[1] - 4.0) < 0.2
    assert abs(ext[2] - 2.0) < 1e-6

def test_raises_with_too_few_slices():
    with pytest.raises(ValueError):
        loft_slices_to_mesh([SliceResult(z_mm=0.0, polygon=square(2.0))])
```

- [ ] **Step 2: Run test to verify it fails**

Run: `pytest tests/reconstruction/test_mesh.py -v`
Expected: FAIL (`ModuleNotFoundError: gemscanner.reconstruction.mesh`)

- [ ] **Step 3: Write the implementation**

```python
# gemscanner/reconstruction/mesh.py
import numpy as np
import trimesh
from gemscanner.geometry.polygon import polygon_centroid, polygon_area, ray_radius

def _largest_contiguous(slices):
    best = (0, 0)
    cur_start = None
    for i, s in enumerate(slices):
        if s.polygon is not None and polygon_area(s.polygon) > 1e-9:
            if cur_start is None:
                cur_start = i
            if i - cur_start + 1 > best[1] - best[0]:
                best = (cur_start, i + 1)
        else:
            cur_start = None
    return slices[best[0]:best[1]]

def loft_slices_to_mesh(slices, n_radial=180):
    run = _largest_contiguous(slices)
    if len(run) < 2:
        raise ValueError("need at least two non-empty slices to build a mesh")

    angles = np.linspace(0, 2 * np.pi, n_radial, endpoint=False)
    rings = []
    for s in run:
        c = polygon_centroid(s.polygon)
        pts = np.array([
            c + ray_radius(s.polygon, c, a) * np.array([np.cos(a), np.sin(a)])
            for a in angles
        ])
        rings.append(np.column_stack([pts[:, 0], pts[:, 1],
                                      np.full(n_radial, s.z_mm)]))
    rings = np.array(rings)               # (M, n_radial, 3)
    M = len(rings)
    vertices = rings.reshape(-1, 3)

    faces = []
    for k in range(M - 1):
        for j in range(n_radial):
            j2 = (j + 1) % n_radial
            a = k * n_radial + j
            b = k * n_radial + j2
            c = (k + 1) * n_radial + j
            d = (k + 1) * n_radial + j2
            faces.append([a, b, d])
            faces.append([a, d, c])

    bottom_c = len(vertices)
    top_c = bottom_c + 1
    bottom_center = np.array([rings[0, :, 0].mean(), rings[0, :, 1].mean(),
                              rings[0, 0, 2]])
    top_center = np.array([rings[-1, :, 0].mean(), rings[-1, :, 1].mean(),
                           rings[-1, 0, 2]])
    vertices = np.vstack([vertices, bottom_center, top_center])

    base = (M - 1) * n_radial
    for j in range(n_radial):
        j2 = (j + 1) % n_radial
        faces.append([bottom_c, j2, j])               # bottom cap
        faces.append([top_c, base + j, base + j2])    # top cap

    mesh = trimesh.Trimesh(vertices=vertices, faces=np.array(faces), process=True)
    mesh.fix_normals(multibody=False)   # single-body mesh; avoids a scipy dependency
    return mesh
```

- [ ] **Step 4: Run test to verify it passes**

Run: `pytest tests/reconstruction/test_mesh.py -v`
Expected: PASS

- [ ] **Step 5: Commit**

```bash
git add gemscanner/reconstruction/mesh.py tests/reconstruction/test_mesh.py
git commit -m "feat: loft slice cross-sections into a watertight mesh"
```

---

### Task 12: Pipeline + mesh export (`reconstruction/pipeline.py`, `storage/mesh_io.py`)

**Files:**
- Create: `gemscanner/storage/mesh_io.py`
- Create: `gemscanner/reconstruction/pipeline.py`
- Test: `tests/storage/test_mesh_io.py`
- Test: `tests/reconstruction/test_pipeline.py`

**Interfaces:**
- Consumes: `storage.dataset.load_dataset`, `reconstruction.strip_intersection.StripIntersectionReconstructor`, `reconstruction.base.ReconstructionParams`, `trimesh`.
- Produces:
  - `export_mesh(mesh, path)` — writes `.stl` / `.ply` / `.obj` by extension.
  - `reconstruct_dataset(dataset_path, params=None) -> trimesh.Trimesh`.

- [ ] **Step 1: Write the failing tests**

```python
# tests/storage/test_mesh_io.py
import os
import trimesh
from gemscanner.storage.mesh_io import export_mesh

def test_export_stl(tmp_path):
    mesh = trimesh.creation.box(extents=(2, 2, 2))
    out = tmp_path / "box.stl"
    export_mesh(mesh, str(out))
    assert os.path.exists(out)
    reloaded = trimesh.load(str(out))
    assert reloaded.is_watertight
```

```python
# tests/reconstruction/test_pipeline.py
from gemscanner.synthetic.generator import generate_ellipsoid_scan
from gemscanner.reconstruction.pipeline import reconstruct_dataset

def test_reconstruct_dataset_returns_mesh(tmp_path):
    out = generate_ellipsoid_scan(str(tmp_path / "scan"), rx=4, ry=3, rz=5,
                                  n_views=120, mm_per_px=0.05, width=400, height=400)
    mesh = reconstruct_dataset(out)
    assert mesh.is_watertight
    assert mesh.volume > 0
```

- [ ] **Step 2: Run tests to verify they fail**

Run: `pytest tests/storage/test_mesh_io.py tests/reconstruction/test_pipeline.py -v`
Expected: FAIL (`ModuleNotFoundError` for `mesh_io` / `pipeline`)

- [ ] **Step 3: Write the implementations**

```python
# gemscanner/storage/mesh_io.py
def export_mesh(mesh, path):
    """Write a mesh to .stl/.ply/.obj (format inferred from the file extension)."""
    mesh.export(path)
```

```python
# gemscanner/reconstruction/pipeline.py
from gemscanner.storage.dataset import load_dataset
from gemscanner.reconstruction.strip_intersection import StripIntersectionReconstructor
from gemscanner.reconstruction.base import ReconstructionParams

def reconstruct_dataset(dataset_path, params=None):
    dataset = load_dataset(dataset_path)
    params = params or ReconstructionParams()
    return StripIntersectionReconstructor().reconstruct(dataset, params)
```

- [ ] **Step 4: Run tests to verify they pass**

Run: `pytest tests/storage/test_mesh_io.py tests/reconstruction/test_pipeline.py -v`
Expected: PASS

- [ ] **Step 5: Commit**

```bash
git add gemscanner/storage/mesh_io.py gemscanner/reconstruction/pipeline.py tests/storage/test_mesh_io.py tests/reconstruction/test_pipeline.py
git commit -m "feat: reconstruction pipeline and mesh export"
```

---

### Task 13: End-to-end accuracy (centered, off-center, asymmetric)

**Files:**
- Test: `tests/test_end_to_end.py`

**Interfaces:**
- Consumes: `synthetic.generator.generate_ellipsoid_scan`, `reconstruction.pipeline.reconstruct_dataset`.
- Produces: nothing (verification only). Proves the spec's §9 success criteria for dimensional accuracy, off-center, and asymmetric gems.

- [ ] **Step 1: Write the failing test**

```python
# tests/test_end_to_end.py
import numpy as np
from gemscanner.synthetic.generator import generate_ellipsoid_scan
from gemscanner.reconstruction.pipeline import reconstruct_dataset

TOL = 0.3   # mm; ~6 px at 0.05 mm/px, covers discretization + radial resampling

def _extents(out):
    return reconstruct_dataset(out).bounding_box.extents

def test_centered_dimensions(tmp_path):
    out = generate_ellipsoid_scan(str(tmp_path / "c"), rx=4, ry=3, rz=5,
                                  n_views=180, mm_per_px=0.05, width=400, height=400)
    ext = _extents(out)
    assert abs(ext[0] - 8.0) < TOL
    assert abs(ext[1] - 6.0) < TOL
    assert abs(ext[2] - 10.0) < TOL

def test_off_center_recovers_size_and_offset(tmp_path):
    out = generate_ellipsoid_scan(str(tmp_path / "o"), rx=4, ry=3, rz=5,
                                  n_views=180, mm_per_px=0.05, width=400, height=400,
                                  center_offset=(2.0, 1.0))
    mesh = reconstruct_dataset(out)
    ext = mesh.bounding_box.extents
    assert abs(ext[0] - 8.0) < TOL and abs(ext[1] - 6.0) < TOL
    # reconstruction is in the object frame: center recovered at the offset
    cx, cy, _ = mesh.bounding_box.centroid
    assert abs(cx - 2.0) < TOL and abs(cy - 1.0) < TOL

def test_asymmetric_shape(tmp_path):
    out = generate_ellipsoid_scan(str(tmp_path / "a"), rx=5, ry=2, rz=5,
                                  n_views=180, mm_per_px=0.05, width=400, height=400)
    ext = _extents(out)
    assert abs(ext[0] - 10.0) < TOL
    assert abs(ext[1] - 4.0) < TOL
```

- [ ] **Step 2: Run test to verify it fails (or passes if all prior tasks complete)**

Run: `pytest tests/test_end_to_end.py -v`
Expected: PASS once Tasks 1–12 are implemented. If any assertion fails, debug the responsible module (do **not** loosen `TOL` without cause).

- [ ] **Step 3: Run the full suite**

Run: `pytest -v`
Expected: ALL PASS

- [ ] **Step 4: Commit**

```bash
git add tests/test_end_to_end.py
git commit -m "test: end-to-end reconstruction accuracy for centered, off-center, asymmetric gems"
```

---

## Self-Review

**Spec coverage (against the design spec §4–§9):**
- §4.1 Approach A strip intersection → Tasks 3, 4, 10, 11.
- §4.3 off-center & asymmetric, registered-to-axis (never re-centered) → Task 13 (`test_off_center_*`, `test_asymmetric_shape`); reconstruction works in the object frame with no per-frame recentering.
- §4.2 Approach-B seam → `Reconstructor` is duck-typed (`reconstruct(dataset, params)`); a future `VoxelCarver` implements the same method, consumed by `pipeline.reconstruct_dataset` unchanged.
- §5.3 dataset = frames + `manifest.json` → Tasks 5, 8.
- §7 calibration fields (mm_per_px, axis_column, axis_tilt, eccentricity) live in `ScanManifest` and are consumed by `coords`/`strip_intersection` (Tasks 2, 10).
- Mesh export STL/PLY/OBJ → Task 12.
- **Deferred to Plan C (correctly out of scope here):** real camera backends, motion/ESP32, `ScanController`, pre-scan FoV check, live calibration capture, CLI/Open3D viewer. The `vision.extract_silhouette(holder_mask_rows=…)` hook and `ReconstructionParams.holder_mask_rows` are present so Plan C can supply holder masking without reopening this code.

**Placeholder scan:** No TBD/TODO; every code step contains complete implementations and concrete test assertions.

**Type consistency:** Verified `clip_convex_polygon(polygon, normal, offset)`, `ray_radius(polygon, center, angle)`, `extract_silhouette(image, threshold, holder_mask_rows)`, `row_spans(mask)`, `SliceResult(z_mm, polygon)`, `ReconstructionParams(n_radial, holder_mask_rows, threshold, bbox_mm)`, and `loft_slices_to_mesh(slices, n_radial)` are used with identical names/signatures across producing and consuming tasks. The slab normal `(cos θ, -sin θ)` and the `projection_to_column`/`column_to_projection` pair are shared between the generator (Task 6) and reconstructor (Task 10), guaranteeing the forward/inverse models match.

---

## Execution Handoff

Plan complete and saved to `docs/superpowers/plans/2026-06-24-plan-a-reconstruction-core.md`. Two execution options:

1. **Subagent-Driven (recommended)** — I dispatch a fresh subagent per task, review between tasks, fast iteration.
2. **Inline Execution** — Execute tasks in this session using executing-plans, batch execution with checkpoints.

Which approach?

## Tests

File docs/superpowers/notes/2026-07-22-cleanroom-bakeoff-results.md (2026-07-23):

# Clean-room silhouette → faceted-gemstone bake-off: results + recommendation

Date: 2026-07-22. Branch: `feat/cleanroom-silhouette-facet-bakeoff`.
Spec: `docs/superpowers/specs/2026-07-22-clean-room-silhouette-to-facet-design.md`.
Harness: `scratchpad/cleanroom/bakeoff.py` (+ `render.py`).

## 1. What this was and why

This was a **clean-room re-derivation** of the silhouette → faceted-convex-polytope
reconstruction problem, done deliberately without reusing or extending
`gemscanner/reconstruction/`. The shipped `method="facet"` pipeline (v2.3) is
already merged and user-signed-off on `gem04` (56 planes, watertight, 5 µm
median facet RMS, extents X+16/Y+40/Z+77 µm vs `gem.stl`). The user asked for
an independent investigation anyway: re-derive the problem from first
principles, survey what the literature offers, and empirically bake off the
most promising method families against the same real scan — to learn whether
an independent approach matches, beats, or teaches something the shipped one
does not (notably the residual Z +77 µm gap).

The investigation was run as **survey → down-select → three candidates +
negative control, benchmarked against v2.3** (v2.3 is a benchmark to
match/beat, not one of the three candidates under test). All three
candidates and the control consume only the same clean-room support-function
front-end (`h(θ,z)`, rebuilt independently from the raw silhouettes) and
produce a mesh with no import from `gemscanner/reconstruction/`.

## 2. The survey table (from the design spec)

| # | Family | Core idea | Strike-line-prone? | Fit for this rig |
|---|---|---|:---:|---|
| 1 | Space carving / per-slice visual hull | Intersect back-projected silhouette cones on a voxel/slice grid | **Yes** (each layer independent) | The known failure; keep only as negative control |
| 2 | Support-function half-space fitting | Detect facet directions, fit affine `h(θ,z)=β+αz` per facet, intersect half-spaces | No (planes span all z) | The shipped v2.3; strong fit — the benchmark |
| 3 | Dual-space convex reconstruction | Each tangent plane = a point in polar-dual space; body = polar dual of dual-point hull; merge near-coplanar faces | No (global convex hull) | Elegant, nearly parameter-free, exploits convexity directly |
| 4 | Tangent-plane RANSAC | Every (edge point, local tangent) votes a plane hypothesis; RANSAC/cluster in plane-parameter space | No (planes global) | Robust, standard, assumption-light |
| 5 | EGI / Minkowski (normals + areas) | Cluster tangent normals on the Gauss sphere → facet normals, then solve offsets | No | Clean for convex polytopes; offset solve is fiddly |
| 6 | Parametric cut template | Fit a known brilliant/step-cut model to silhouettes | No | Robust *if* cut known; fails on irregular cuts — too specific |
| 7 | Differentiable silhouette rendering (SDF/mesh + planarity prior) | Optimize a surface so rendered silhouettes match, regularized to planarity | No | Modern but disproportionate to a benchtop tool — future work |

**Down-select rationale.** Families 2/3/4/5 are the strike-line-free,
convexity-exploiting contenders — all fit a model that spans *z*, so none has
a per-row degree of freedom left to strike (see §3). Family 2 is already the
shipped benchmark, so the three clean-room candidates were drawn from
families 3, 4, 5:

- **Cand-A** — Tangent-plane RANSAC (family 4): every silhouette edge point +
  local tangent votes a 3D plane hypothesis; cluster in (normal, offset)
  space; intersect the winning half-spaces.
- **Cand-B** — Dual-space convex reconstruction (family 3): tangent planes →
  dual points → convex hull → dualize back → merge near-coplanar faces.
  Nearly parameter-free; the cleanest expression of "the gem is convex."
- **Cand-C** — EGI / Gauss-sphere clustering (family 5): cluster tangent
  normals on the sphere to get facet *directions* first, then solve each
  offset from its support samples (direction-first vs point/plane-first).

Family 6 (parametric cut template) and Family 7 (differentiable rendering)
were recorded but explicitly out of scope — too cut-specific / disproportionate
to a benchtop tool.

## 3. The root-cause principle for strike-lines (the sorting axis)

A horizontal strike-line is a **z-to-z inconsistency**: consecutive height
rows land at radii that disagree by noise ε because each row was decided from
its own silhouette edges *independently*. Space-carving and per-slice visual
hull do exactly this — every z-layer is an independent 2D decision, so
silhouette edge noise is written straight into a horizontal ridge.

> **Principle that eliminates strike-lines:** never fix a surface point from a
> single row in isolation. Any method that fits a model spanning *z* — an
> affine support piece, a global plane, a parametric cut, an implicit surface
> — averages per-row noise into the fit and has no per-row degree of freedom
> left to strike.

Every family in the survey table is sorted on this one axis, and it is the
whole reason families 2–5 were candidates in the first place while family 1
is kept only as the negative control.

## 4. The bake-off metrics table (harness output on gem04, verbatim)

```
$ .venv/Scripts/python.exe -m scratchpad.cleanroom.bakeoff
building support samples...
support grid: 1944 rows x 180 views (333 rows have any valid data) -- no subsampling applied (see module docstring)
rms_tol_mm = 0.7 for all three candidates (retuned from 0.15; see module docstring)
Cand-A RANSAC: 216 tangent facets, watertight=True, 2.0s -> scratchpad/cleanroom/cand_a_gem04.stl
Cand-B dual: 20 tangent facets, watertight=True, 0.9s -> scratchpad/cleanroom/cand_b_gem04.stl
Cand-C EGI: 84 tangent facets, watertight=True, 9.1s -> scratchpad/cleanroom/cand_c_gem04.stl
CONTROL strip: 116640 faces, watertight=True, 15.3s
BENCH v2.3: 208 faces, watertight=True, 17.5s

wrote scratchpad/cleanroom/bakeoff_gem04.png
total wall-clock: 61.3s
```

| method | facets | watertight | dX (µm) | dY (µm) | dZ (µm) | rmsMed (µm) | strike (µm) | sec |
|---|---:|:--:|---:|---:|---:|---:|---:|---:|
| Cand-A RANSAC | 216 | True | +1532 | +1075 | +159 | 411.5 | 0.0 | 2.0 |
| Cand-B dual | 20 | True | +1845 | +1210 | +151 | 341.1 | 0.0 | 0.9 |
| Cand-C EGI | 84 | True | +645 | +401 | −226 | 353.6 | 0.0 | 9.1 |
| CONTROL strip | 116640 | True | +1 | −1 | −2 | -- | **6.8** | 15.3 |
| BENCH v2.3 | 208 | True | +16 | +40 | +77 | -- | 0.0 | 17.5 |

(`d*` = extents delta vs `scans/gem04/gem.stl`, µm; `strike` = strike-line
high-pass energy, µm; reference `gem.stl`: extents `[8.338, 7.837, 5.501]` mm,
volume 137.18 mm³, watertight, 116640 faces, 58322 vertices.)

Reproduced independently by the reviewer during Task 7 review, byte-for-byte:
strike energy for CONTROL = 6.822677793901232 µm; every candidate/benchmark
strike energy ≈ 5.7e-13 µm (genuinely zero, not a NaN artifact).

**Caveat on `rmsMed`: not comparable to v2.3's 5 µm figure.** The `rmsMed`
column above (411.5 / 341.1 / 353.6 µm) and §1's "5 µm median facet RMS" for
v2.3 are **different metrics** computed differently, and a reader will
otherwise wrongly conclude the candidates are ~80× worse at facet fitting
than v2.3. Running the clean-room `facet_rms` on the **shipped v2.3 planes**
(from `scans/gem04/gem_facet_v23_preview.stl`) over the same real gem04
support samples gives:
```
n=54 planes: min 0.208 mm, median 0.612 mm, max 5.669 mm
fraction <= 0.15 mm: 0.00   fraction <= 0.70 mm: 0.59
```
i.e. v2.3's own signed-off facets score *worse* on this metric than every
candidate's median. `rmsMed` here is a relative, within-this-table gate
only; it is **not** comparable to v2.3's per-z-band 5 µm figure and must not
be read as a quality ranking against v2.3.

## 5. The headline result: the strike metric separates on real data

**Confirmed, and by a wide margin.** CONTROL strip (space-carving,
per-row-independent) scores **6.8 µm** strike energy. Every faceted method —
Cand-A, Cand-B, Cand-C, and BENCH v2.3 — scores **0.0 µm**. This is corroborated
visually in `scratchpad/cleanroom/bakeoff_gem04.png` (panels: `gem.stl`,
Cand-A, Cand-B, Cand-C, CONTROL strip, BENCH v2.3): the CONTROL panel is
densely terraced (visibly rougher/fuzzier, especially on the near-vertical
girdle walls), while Cand-A/B/C and BENCH v2.3 all show clean, flat facets
with sharp edges and no visible striping. The central hypothesis of the whole
investigation — that per-row-independent carving writes noise into
horizontal ridges, and any model spanning z averages it out — **holds** on
real, noisy, full-resolution scan data, exactly as it held on the earlier
synthetic fixtures (`gemscanner-striation-fix` memory).

## 6. The major methodological finding: `gem.stl` is not independent ground truth

**`scans/gem04/gem.stl` is not an independent dimensional reference.**
Applying this repo's own Taubin smoother to a freshly regenerated strip
reconstruction reproduces `gem.stl` **exactly**:
`smooth_mesh(reconstruct_dataset("scans/gem04", method="strip", holder_mask_rows=705), 10)`
matches `scans/gem04/gem.stl` to a nearest-neighbour max distance of
**0.0000 mm** over all 58322 vertices, with identical extents and identical
strike energy. `gem.stl` is regenerable today via this repo's own
`gemscanner scan --smooth 10` (`gemscanner/cli.py`).

Measured ladder:
```
taubin  0: nn med 0.0028 max 0.0178 mm | uniq_z   324 | strike 6.823 | ext [8.3387 7.8361 5.4980]
taubin  5: nn med 0.0005 max 0.0075 mm | uniq_z 58317 | strike 1.511 | ext [8.3397 7.8356 5.5029]
taubin 10: nn med 0.0000 max 0.0000 mm | uniq_z 58317 | strike 1.256 | ext [8.3381 7.8366 5.5005]
gem.stl  :                              uniq_z 57739 | strike 1.256 | ext [8.3381 7.8366 5.5005]
```

The reference is a **Taubin-smoothed** visual hull — this is why `gem.stl`
strikes 1.256 µm while the fresh strip control (unsmoothed) strikes 6.8 µm:
smoothing reduces strike energy but does not eliminate it (§4-5's CONTROL row
above is the unsmoothed version of the same reconstruction). The note's own
table evidence corroborates this from a different angle: CONTROL strip is
only +1/−1/−2 µm from `gem.stl` in extents — consistent with both being the
same underlying reconstruction at different smoothing levels, not
independent measurements.

Note that the vertex count is **not** independent evidence for this claim:
for any watertight genus-0 triangle mesh, V = F/2 + 2 exactly
(116640/2 + 2 = 58322), so "matching face and vertex counts" is one
statistic, not two, and a skeptic can further object that the fresh strip
mesh has 324 unique z-levels vs `gem.stl`'s 57739 (resolved above by the
smoothing ladder: Taubin smoothing raises unique-z from 324 to 58317,
consistent with `gem.stl`'s 57739). The argument for provenance rests
entirely on the exact reproduction (0.0000 mm nearest-neighbour distance),
not on face/vertex counts.

**Consequence, stated plainly:** every "extents delta vs `gem.stl`" number in
this investigation — and in the shipped v2.3 validation, including its
**±50 µm G3 acceptance gate** — measures agreement with a visual-hull
reconstruction of the same scan, not agreement with the true physical stone.
A candidate or benchmark can score well on this metric purely by resembling
another space-carved reconstruction of identical input data. An independent
physical measurement (CMM, certificate, or hand micrometer on facet
dimensions) would be required for the extents/G3 numbers to mean what they
appear to mean. This applies retroactively to v2.3's own sign-off, not just to
this bake-off. It does not mean the shape/volume comparison is worthless (it
is still a reasonable proxy for gross correctness), but the precision implied
by a ±50 µm gate against this particular reference is not established.

This is arguably the single most valuable output of the whole investigation,
and it was not something either candidate accuracy or the strike metric was
designed to surface — it fell out of simply checking the reference mesh's own
provenance.

## 7. The honest negative results

- **Candidates are 2×–115× less accurate than v2.3 depending on axis (worst
  in X/Y, closest in Z) on real data.** v2.3: dX/dY/dZ = +16/+40/+77 µm.
  Candidates: Cand-A +1532/+1075/+159, Cand-B +1845/+1210/+151, Cand-C
  +645/+401/−226 µm. The spread is axis-dependent, not uniform: dZ is the
  closest axis (159 vs v2.3's 77 = 2.1×; 151 = 2.0×; −226 = 2.9×), while dX is
  the worst (Cand-B: 1845 vs v2.3's 16 = 115×). All three are systematically
  *larger* than `gem.stl` in X/Y, not merely noisier.

- **All three needed `rms_tol_mm` loosened 0.15 → 0.7 uniformly just to
  produce a mesh at all.** At 0.15 (the value tuned on exact, noise-free
  synthetic fixtures) all three fail outright on real gem04 data:
  `planes_to_mesh` raises `ValueError` because the raw half-space hypotheses
  don't bound a closed region (Cand-A: 3 tangent facets survive; Cand-B: 0;
  Cand-C: 1). The same 0.7 mm was applied to all three so the comparison
  stayed apples-to-apples, not tuned per-candidate to flatter it — reported
  even though the resulting facet counts (216/20/84) are wildly different at
  equal tolerance. The tolerance sweep that justified 0.7 mm (from the
  investigation's working task-7 notes, inlined here so it survives the
  session's working artifacts):
  ```
  | tol | Cand-A RANSAC | Cand-B dual | Cand-C EGI |
  |---|---|---|---|
  | 0.15 | FAIL (3 tangent facets survive) | FAIL (0 facets survive) | FAIL (1 facet survives) |
  | 0.30 | OK, 53 facets, ext=[12.74,10.79,5.65]mm | OK, 8 facets, ext=[13.31,10.85,5.85]mm | OK, 25 facets, ext=[11.69,10.31,5.62]mm |
  | 0.50 | OK, 166 facets, ext=[10.63,9.25,5.59]mm | OK, 16 facets, ext=[10.72,9.64,5.66]mm | OK, 59 facets, ext=[10.39,9.15,5.39]mm |
  | 0.70 | OK, 216 facets, ext=[9.87,8.91,5.66]mm | OK, 20 facets, ext=[10.18,9.05,5.65]mm | OK, 84 facets, ext=[8.98,8.24,5.27]mm |
  | 1.00 | OK, 255 facets, ext=[9.72,8.90,5.60]mm | OK, 20 facets, ext=[10.18,9.05,5.65]mm (unchanged from 0.70) | OK, 88 facets, ext=[8.82,8.24,5.14]mm |
  ```
  `0.7` was picked from the raw (pre-merge, pre-filter) `facet_rms`
  distributions, not by trial-and-error against the final table: Candidate B
  shows a clean gap (21 clusters at rms<=0.65mm real facets, 3 at
  rms in [1.39, 1.58]mm girdle-crossing artifacts, 7 at rms>=4.7mm gross
  outliers — 0.7mm sits in the gap); Candidates A and C have no such clean
  gap (continuous from ~0.12mm to ~1.8-2.3mm before a jump to garbage above
  ~3.5-4.7mm) but their mesh extents stabilize (diminishing marginal change)
  once tol reaches ~0.7-1.0mm, and 0.7 is the conservative end of that
  plateau. **Correction to the cause:** `bakeoff.py`'s module
  docstring attributes the non-zero rms floor to "real silhouette
  threshold/quantization noise" — the §4 `rmsMed` caveat above refutes this: the
  exact, accurate, shipped v2.3 planes *also* score 0.208–5.669 mm on the
  same metric over the same real data, so noise in the input is not the
  cause. The actual floor is set by `facet_rms`'s own construction: it
  averages residuals over the *entire* valid z-column within a ±6° azimuth
  band, while a real gem facet occupies only a small z-band within a
  333-row column — the synthetic bipyramid used to tune 0.15 mm had facets
  spanning half the column, which is why that tolerance never transferred to
  real facet geometry. The retune itself (uniform across all three
  candidates, honestly reported) is correct and stands; only the stated
  cause is wrong.

- **The girdle prediction held, and generalized.** `gem.stl`'s girdle facets
  are genuinely near-vertical (3538/116640 faces, ~3% of face count and
  surface area, have `|normal_z| < 0.15`). At `rms_tol_mm=0.7`, **all three
  candidates emit zero near-vertical facets** (min `|alpha|`: A=0.383,
  B=0.429, C=0.413) — via two distinct mechanisms: Candidate A *does*
  generate near-vertical raw hypotheses (35 of 1474), but every one has
  `facet_rms` in [1.27, 1.69] mm, well above the 0.7 mm tolerance, so the same
  gate needed to reject garbage also kills genuine thin girdle facets;
  Candidates B and C never propose a near-vertical hypothesis in the first
  place. This was originally flagged (Task 5) as a Candidate-A-specific risk
  from `kink_step_deg=15°`, but it turned out to be a structural blind spot
  shared by all three clean-room methods on real, noisy data near thin
  facet bands.

- **Candidate offset asymmetry — the corrected finding.** Only Candidate A
  (`cand_a_ransac.py:121`) and Candidate B (`cand_b_dual.py:107`) use
  envelope max-snap (`β = max_z(h(θ,z) − αz)`), which is a *guaranteed
  supporting tangent* — the resulting half-space intersection can never carve
  real volume away, only expand outward. Candidate C uses a **median-based**
  offset (`β = median(h − αz)`, `cand_c_egi.py:110`), which is not a
  guaranteed tangent. Correspondingly, Candidate C has the smallest X/Y error
  of the three (+645/+401 µm vs A's +1532/+1075 and B's +1845/+1210), but is
  the *only* candidate with a **negative** dZ (−226 µm) — its median offset
  can and does place a plane inside the true body, carving real volume away,
  something the max-snap methods structurally cannot do. This is a genuine
  accuracy-vs-safety trade-off between the candidates, and the bake-off did
  **not** equalize it — each `reconstruct_*` was called unmodified. A future
  comparison should either equalize the offset estimator across all three or
  report this explicitly, as done here.

- **The plan's own reference algorithms for EGI (Cand-C) and RANSAC (Cand-A)
  were geometrically wrong as originally specified.** Naive per-azimuth
  `dh/dz` tracks the *shared edge* between two facets (the arris), not either
  facet's own normal — the same "facet vs arris" trap the shipped v2.1
  pipeline independently had to solve. Both implementers rediscovered this
  and fixed it independently (Cand-C: local-minima-of-`|dh/dz|` azimuth
  filter; Cand-A: full-azimuth kink mask at facet-spacing step + envelope-snap
  offset instead of least-squares).

- **The controller's original strike metric was itself wrong** on the first
  attempt: a median-filter high-pass false-positived at facet slope-kinks —
  a clean, sloped bipyramid (no striping at all) read ~5 µm. It was replaced
  with a median-of-second-difference (`d2 = r[i-1] - 2r[i] + r[i+1]`,
  aggregated by median absolute value), which reads exactly 0 µm on any
  straight facet, flat or sloped, and only lights up on genuine per-row
  disagreement.

- **Known metric limitation, carried forward:** `median(|d2|)` has a 50%
  breakdown point per azimuth — striping affecting fewer than half an
  azimuth's rows reads as 0. This is valid for this investigation (the strip
  control strikes pervasively, on nearly every row) but is **not** a valid
  detector for localized or partial striping.

- **Candidates A and C are not fully independent methods.** Both share the
  "kink"/local-minimum-of-slope azimuth-selection principle and the same
  `rms_tol_mm` gate value. The bake-off should be read as two genuinely
  distinct approaches (B: primal convex-hull geometry, no differentiation;
  A/C: numerical differentiation of the support grid with slightly different
  clustering) plus a shared-lineage variant, not three independent methods.

## 8. Per-candidate verdict and recommendation

| candidate | watertight | strike-free (metric+visual) | extents vs v2.3 | girdle facets | independence | notes |
|---|:--:|:--:|---|:--:|---|---|
| Cand-A RANSAC | Yes | Yes (0.0 µm, clean render) | 2×–115× worse (depending on axis) | None (gate kills near-vertical hyps) | shares kink+tol with C | most facets (216), slowest to tune-fail, safest offset (max-snap) |
| Cand-B dual | Yes | Yes (0.0 µm, clean render) | 2×–115× worse (worst of the three) | None (never generated) | genuinely distinct | fewest facets (20), fastest (0.9s), cleanest/most parameter-free method, safest offset (max-snap) |
| Cand-C EGI | Yes | Yes (0.0 µm, clean render) | 2×–115× worse (best of the three) | None (never generated) | shares kink+tol with A | slowest (9.1s), best X/Y accuracy but only candidate that can carve inward (median offset) |

**Recommendation: v2.3 remains the production method.** No candidate beats it
on dimensional accuracy, and none closes the residual Z +77 µm gap that
motivated the investigation — if anything, all three are 2×–115× further
from `gem.stl` than v2.3 already is, depending on axis (worst in X/Y, closest
in Z). This is reported plainly, not softened:
the investigation's value here is the comparison itself, not a forced win.
Nothing from Candidates A, B, or C should be ported into
`gemscanner/reconstruction/` as a replacement algorithm.

What the clean-room investigation *did* produce that is worth keeping:

- **(a) The strike-line metric as a reusable objective regression gate.**
  `strike_metric.strike_energy` (median-of-second-difference along z,
  per-azimuth) cleanly separates striped from clean meshes on real data (6.8
  µm vs 0.0 µm) and is cheap to compute. This is worth porting into the
  shipped pipeline's own test/validation suite as an automated regression
  check against re-introducing strike-lines — subject to its known 50%
  breakdown-point limitation (§7).
- **(b) The envelope-snap tangency property as a principled offset
  estimator**, worth keeping in mind for any future offset-fitting work: `β =
  max_z(h(θ,z) − αz)` is provably a supporting half-space (never carves real
  volume, only ever expands outward), a useful safety property distinct from
  a least-squares or median fit that can bias either direction. This is an
  idea worth remembering, not code to port — v2.3 already uses an exact
  frozen refit (`fit_affine_support`→`plane_from_affine`) suited to its own
  segmentation, and swapping in envelope-snap was not tested against v2.3's
  architecture here.
- **(c) The `gem.stl`-is-not-ground-truth finding (§6)**, which is arguably
  the most valuable output of this entire investigation, independent of any
  candidate's performance. It should inform how the ±50 µm G3 gate and any
  future extents-based acceptance criteria are described and trusted, and
  motivates seeking an independent physical reference for gem04 (or any
  future stone) before treating extents-vs-`gem.stl` as an accuracy claim
  rather than a self-consistency check.
- **(d) The girdle-facet blind spot as a known limitation to test for.** Any
  future faceted-reconstruction method (clean-room or production) should be
  explicitly checked for near-vertical/thin-facet recovery on real noisy
  data — this bake-off shows it is easy for a method to look correct on
  synthetic fixtures and still silently drop the entire girdle band on a
  real scan, by more than one mechanism.

None of the three candidate implementations, their tuned tolerances, or their
offset estimators should be ported into `gemscanner/reconstruction/` as-is;
they remain clean-room reference prototypes in `scratchpad/cleanroom/`.

## 9. Reproduction

```bash
.venv/Scripts/python.exe -m scratchpad.cleanroom.bakeoff
.venv/Scripts/python.exe -m pytest scratchpad/cleanroom/ -v   # 15 passed
```

Harness code: `scratchpad/cleanroom/support_samples.py`, `polytope.py`,
`strike_metric.py`, `cand_a_ransac.py`, `cand_b_dual.py`, `cand_c_egi.py`,
`bakeoff.py`, `render.py`. Comparison render:
`scratchpad/cleanroom/bakeoff_gem04.png`. Per-task briefs, reports, and a
controller ledger were kept as working artifacts of this investigation
session under `.superpowers/sdd/` (task-{1..7}-brief/report.md,
`progress.md`); these are git-ignored working notes, not committed record —
the durable findings they document are captured in this note (notably the
tolerance-sweep table inlined in §7 and the `gem.stl` reproduction evidence
in §6).

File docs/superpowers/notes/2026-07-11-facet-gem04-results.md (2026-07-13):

# Task 9: facet method validation on real gem04 scan

Date: 2026-07-11 (research/run date; see repo log for actual commit date)

## Verdict (one line)

Facet recovery **succeeded** (no fallback to soft_hull) on the real gem04 scan
and produced a watertight 43-facet polyhedron whose median per-facet fit
residual (32.8 µm) beats the 68 µm terracing baseline, **but** it is only
dimensionally faithful to `gem.stl` to within a few **hundred** µm (X +538 µm
/ +6.4%, Y +430 µm / +5.5%, Z +150 µm / +2.7%), not the "few tens of µm"
the design hoped for — and roughly a quarter of individual facets (11/41) have
fit residuals above the 68 µm baseline, so the result is real but imperfect.

## Critical pre-condition found: `holder_mask_rows` must be set

The very first run (script with `ReconstructionParams(method="facet")` and no
`holder_mask_rows`, i.e. default 0) "succeeded" mechanically — no
`RuntimeWarning`, `mesh.metadata["facets"]` populated — but the result was
garbage: only **10 facets**, extents **52.29 x 46.96 x 12.06 mm** vs
`gem.stl`'s **8.34 x 7.84 x 5.50 mm** (~5-6x too large). Root cause: gem04's
raw silhouette includes the pedestal post and stage below the gem (per
`[[gemscanner-bench-calibration]]`, "without it axis fit / FoV / reconstruction
all break"); `holder_mask_rows` defaults to 0 in `ReconstructionParams` and is
not stored in `scans/gem04/manifest.json`, so it must be supplied explicitly
by the caller. This is **not a facet-fit bug** — the same pedestal-inclusive
blow-up reproduces identically with plain `method="strip"` and `method=
"soft_hull"` on the same dataset (41.25 x 41.25 x 17.50 mm for both, matching
each other almost exactly, confirming the issue is upstream of facet-specific
code).

Fix: swept `holder_mask_rows` against `gem.stl`'s known extents using
`method="strip"` (fast) and found **705** reproduces gem.stl's X/Y/Z bounds to
within a few µm (X: 8.3387 vs 8.3381 mm, Y: 7.8361 vs 7.8366 mm, Z bounds
[-5.234..0.962] at hmr=705 give z_min -4.536 vs gem.stl's -4.538 mm). 705 is
exactly the value already documented in `config.example.yaml` ("2026-07-03
gem2 in focus... holder_mask_rows: 705") — so gem04 was evidently scanned
under the same rig/mount calibration as that config comment, it just isn't
recorded in the scan's own manifest. `scripts/validate_facet_gem04.py` now
hardcodes `HOLDER_MASK_ROWS = 705` with a comment explaining why, since the
manifest can't supply it. **This is a real gap**: any dataset lacking a
recorded holder_mask_rows silently reconstructs the pedestal along with the
gem, and nothing currently detects or warns about it.

## Actual script output (after the holder_mask_rows fix)

```
facets=43  vertices(meet-points)=80  edges=234
watertight=True  volume=142.34 mm^3
extents (mm): 8.876 x 8.267 x 5.651
worst on-facet planarity residual: 17.4 um
reference gem.stl extents (mm): [8.33805108 7.83664012 5.50051087]
wrote scans/gem04/gem_facet.stl
```

No `RuntimeWarning` was emitted (facet recovery did not fall back to
soft_hull).

### Caveat on the "planarity residual" metric in the script

The brief's script measures the max distance from mesh *vertices* to each
facet plane (over vertices within 0.02 mm of that plane). For a mesh built by
`HalfspaceIntersection`, every hull vertex sits *exactly* on the ≥3 planes
that define it by construction, so this number (17.4 µm here) mostly reflects
solver/geometric tolerance, not how well a plane fits the real measured
data. The honest per-facet quality number is the affine-fit RMS residual
computed in `recover_planes()` against the raw support-map samples *before*
half-space assembly — obtained by adding debug prints and calling
`seed_facets`/`recover_planes` directly:

> **Reproducibility caveat:** `recover_planes()` computes this `rms` per facet
> but it is *not* threaded into `mesh.metadata["facets"]` (which carries only
> the plane tuples), so `scripts/validate_facet_gem04.py` alone cannot
> regenerate these figures — they require the ad-hoc instrumentation described
> above. Threading `rms` into the metadata is a small follow-up (touches
> production code, hence out of scope for this validation-only task).

- 41 tangent-facet fits (2 more planes are the extremal table/culet, fit
  exactly by definition, rms=0): **median 32.8 µm, mean 49.6 µm, min 4.7 µm,
  max 165.8 µm**.
- 30/41 facets (73%) are below the 68 µm terracing baseline; **11/41 (27%)
  exceed it**, up to 165.8 µm — a real limitation, not universal success.
- Raw Gauss-normal clustering (`seed_facets` before merge/axial-skip)
  returned **53 clusters** on the soft_hull seed mesh; 1 was the near-vertical
  table (routed to the extremal branch), 52 were tangent candidates, and
  **all 52 fit successfully** on the first try (`di=0`, nearest-azimuth view)
  — `facet_min_inliers` and `facet_view_search` never had to fall back to a
  neighboring view or reject a fit for insufficient inliers on this dataset.
  After merge (6°), 41 tangent + 2 extremal = 43 final planes.

## Threshold tuning tried

Reused the same (expensive, ~ minutes) soft_hull seed mesh across all
configs and only re-ran `seed_facets`/`recover_planes`/`planes_to_polytope`
(cheap) for each:

| facet_merge_deg | facet_min_inliers | facet_view_search | n_planes | extents (mm) | rms median / max (µm) | facets over 68µm |
|---|---|---|---|---|---|---|
| 6 (default) | 12 | 4 | 43 | 8.876 x 8.267 x 5.651 | 32.8 / 165.8 | 11/41 |
| 4 | 12 | 4 | 36 | 9.278 x 8.595 x 5.651 | 25.0 / 174.3 | 8/34 |
| 10 | 12 | 4 | 31 | 8.794 x 8.086 x 5.651 | 40.9 / 206.7 | 10/29 |
| 6 | 8 | 4 | 43 | (identical to default) | 32.8 / 165.8 | 11/41 |
| 6 | 20 | 4 | 43 | (identical to default) | 32.8 / 165.8 | 11/41 |
| 6 | 12 | 3 | 43 | (identical to default) | 32.8 / 165.8 | 11/41 |
| 6 | 12 | 6 | 43 | (identical to default) | 32.8 / 165.8 | 11/41 |

Findings:
- `facet_min_inliers` (8/12/20) and `facet_view_search` (3/4/6) have **zero**
  effect on gem04 in the tested ranges — every seed's nearest-azimuth view
  (`di=0`) already had 25-238 inliers, far above even the 20-inlier floor, so
  neither threshold is a binding constraint on this dataset.
- `facet_merge_deg` is the only lever that matters, and it's a genuine
  trade-off, not a free win: looser merging (4°) keeps more, better-individually-fit
  facets (median rms drops to 25.0 µm) but pushes the overall bounding box
  further from `gem.stl` (+940 µm in X). Tighter merging (10°) pulls the
  bounding box closer to `gem.stl` in X/Y (+456 µm / +249 µm, better than
  default) but degrades individual fit quality (median 40.9 µm, max 206.7 µm,
  evidence that some genuinely distinct facets are being merged together).
  No single value in the tested 4-10° range cleanly wins on both axes, so the
  shipped script keeps the pipeline default (6°) rather than picking a value
  post-hoc to make one number look best.
- Z extent (5.651 mm across every config) is set entirely by the two
  extremal table/culet planes, which don't participate in merging, so no
  merge_deg value changes it. Its +150 µm offset from gem.stl (5.501 mm) is a
  separate question from facet clustering — the extremal branch uses the
  bare max/min of `sm.z` over any valid view, which folds in a few extra rows
  of noise/valid-mask slop at the sample extremes; not investigated further
  here (out of scope for "modest tuning of the facet-clustering thresholds").

## Failure modes / limitations found

1. **No manifest-carried `holder_mask_rows`.** gem04's manifest doesn't store
   the pedestal-mask row count used at capture time; a caller must know/guess
   it (here, recovered by sweeping against `gem.stl`). Any future dataset
   missing this value will silently reconstruct pedestal + gem as one blob
   under every method (`strip`, `soft_hull`, `facet` alike) with no error or
   warning — a real gap worth a follow-up (e.g. persist it in the manifest at
   capture time, or add a sanity check comparing silhouette top/bottom widths).
2. **Facet count is plausible but unverified against ground truth.** 43
   facets is a plausible count for a moderately complex cut, but we have no
   independent facet-count ground truth for the physical gem04 stone (unlike
   the synthetic polyhedron test), so "plausible" is as far as this validation
   can honestly go.
3. **~27% of recovered facets have fit residual above the terracing
   baseline** (up to 165.8 µm on the worst outlier), meaning some real
   facets are recovered less well than others — likely narrower/steeper
   facets with fewer usable support-map rows (`n_inliers` as low as 25-50 vs
   ~150-240 for larger facets).
4. **Dimensional fidelity is good but not tight**: +5-6% in X/Y, +2.7% in Z,
   +3.8% in volume vs `gem.stl` — real and repeatable across every merge_deg
   tested, not fixable by the tuning knobs available in this task's scope.
5. **The brief's planarity-residual metric is close to tautological** for a
   half-space-intersection mesh (see caveat above); the meaningful per-facet
   quality signal is the pre-assembly affine-fit RMS, not post-hoc
   vertex-to-plane distance on the final polytope.

## Files

- `scripts/validate_facet_gem04.py` — validation script (hardcodes
  `HOLDER_MASK_ROWS = 705`, required since the manifest doesn't carry it).
- `scans/gem04/gem_facet.stl` — the reconstructed facet mesh from the final
  run (written by the script; not committed to git as source, just a repo
  artifact left in place per the script's own behavior).
- This note.

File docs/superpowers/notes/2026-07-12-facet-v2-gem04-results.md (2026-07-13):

# V2 Task 5: gem04 real-scan validation of the v2.1 faceted reconstruction

Date: 2026-07-12. Branch: `feat/faceted-gem-reconstruction`. Script:
`scripts/validate_facet_gem04.py` (`ReconstructionParams(method="facet",
holder_mask_rows=705)`; `HOLDER_MASK_ROWS = 705` is the rig calibration for
gem04, unrelated to facet detection — see the 2026-07-11 note / memory for how
it was recovered, the manifest still doesn't carry it).

gem04 is scanned **culet-up** (pointed top, flat table at the bottom) and is
not a perfect step cut.

## Verdict (one line)

**5 of 6 gates PASS.** Facet recovery is fast, does not fall back, is
watertight, has excellent per-facet fit quality (median 5.0 µm, well under
the 15 µm gate), and correctly places exactly one table cap with **no culet
cap** (the v1 "flat lid over the culet" bug is gone). The one failing gate is
dimensional fidelity to `gem.stl`: the bounding box is **80–330 µm** off per
axis depending on tuning, which is **1.6×–6.6× over** the ~50 µm/axis gate.
Modest tuning within the brief's specified ranges narrows X from 332 µm to
80 µm but cannot bring all three axes under 50 µm simultaneously, and no
combination tried passes G3. This is reported as a real, unresolved gap, not
papered over.

## Baseline run (default params: `facet_seg_median_rows=17`,
`facet_slope_jump=0.12`, `facet_min_edge_mm=0.35`)

Full captured stdout:

```
facets=41  tangent=40  extremal=1  vertices(meet-points)=78  edges=228
watertight=True  volume=140.14 mm^3
extents (mm): 8.6700 x 7.9967 x 5.5788
reference gem.stl extents (mm): 8.3381 x 7.8366 x 5.5005
extent delta vs gem.stl (um): X=+331.9  Y=+160.1  Z=+78.3
volume delta vs gem.stl: +2.964 mm^3 (+2.16%)
tangent-facet rms (um): median=5.0  max=14.5  min=3.5  n=40
tilt ladder (deg, tangent facets, sorted) with per-facet rms (um):
   -59.19 deg   rms=   6.0 um
   -58.66 deg   rms=   5.1 um
   -57.92 deg   rms=   5.8 um
   -57.84 deg   rms=   5.1 um
   -57.29 deg   rms=   4.9 um
   -57.06 deg   rms=   5.0 um
   -56.49 deg   rms=   4.9 um
   -56.03 deg   rms=   4.8 um
   -54.24 deg   rms=   4.8 um
   +19.95 deg   rms=  14.5 um
   +23.08 deg   rms=   8.0 um
   +23.44 deg   rms=   9.7 um
   +23.88 deg   rms=  12.5 um
   +24.16 deg   rms=   5.3 um
   +24.55 deg   rms=  10.8 um
   +24.93 deg   rms=   4.8 um
   +25.56 deg   rms=   8.8 um
   +25.59 deg   rms=   9.8 um
   +26.03 deg   rms=   4.8 um
   +34.66 deg   rms=   4.9 um
   +37.94 deg   rms=   4.9 um
   +38.19 deg   rms=   4.9 um
   +38.77 deg   rms=   5.2 um
   +39.61 deg   rms=   5.0 um
   +39.64 deg   rms=   5.0 um
   +40.28 deg   rms=   4.8 um
   +40.62 deg   rms=   5.0 um
   +43.55 deg   rms=   4.8 um
   +43.57 deg   rms=   4.7 um
   +44.09 deg   rms=   4.7 um
   +44.99 deg   rms=   5.5 um
   +45.19 deg   rms=   3.5 um
   +46.39 deg   rms=   5.9 um
   +46.93 deg   rms=   4.6 um
   +47.52 deg   rms=   4.9 um
   +49.55 deg   rms=   5.1 um
   +49.94 deg   rms=   5.6 um
   +50.54 deg   rms=   5.3 um
   +53.02 deg   rms=   5.3 um
   +53.47 deg   rms=   4.9 um
extremal planes (source: table/culet caps):
  plane=(+0.0000,+0.0000,-1.0000,+4.5363)  tilt=-90.00 deg  -> BOTTOM/TABLE CAP (c<0)

=== GATE VERDICTS ===
[PASS] G1 no fallback RuntimeWarning (0 fallback warning(s))
[PASS] G2 tangent rms median <= 15.0 um (got 5.0 um)
[FAIL] G3 extents within 50.0 um/axis of gem.stl (worst axis delta 331.9 um)
[PASS] G4 watertight (got True)
[PASS] G5 no culet cap (extremal plane with c>0) (culet_cap_present=False)
[PASS] G6 exactly one table cap (c<0 extremal plane) (got 1)

ALL GATES: FAIL
wrote scans/gem04/gem_facet.stl
```

Wall-clock: the whole reconstruction (support maps + slicing + facet
recovery + half-space assembly) completed in well under a minute, confirming
the brief's "tens of seconds, no soft-hull seed" expectation for v2.1.

## Gate-by-gate

| Gate | Requirement | Result | Verdict |
|---|---|---|---|
| G1 | No fallback `RuntimeWarning` | 0 fallback warnings | **PASS** |
| G2 | Tangent-facet rms median ≤ 15 µm | 5.0 µm (max 14.5 µm, min 3.5 µm, n=40) | **PASS** |
| G3 | Extents within ~50 µm/axis of `gem.stl` | X +331.9, Y +160.1, Z +78.3 µm | **FAIL** |
| G4 | Watertight | `True` | **PASS** |
| G5 | No culet cap (no extremal plane with c>0) | none present | **PASS** |
| G6 | Exactly one table cap (c<0 extremal plane) | 1 (at z=−4.536 mm) | **PASS** |

## Tilt ladder vs the az-74 reference

Reference (one side of the stone, pre-verified): pavilion tiers ≈
+27/+39/+45/+50°, crown ≈ −58°, per-tier rms 4.7–8.0 µm.

Full-stone structure recovered here groups into the same tier bands, each
containing several distinct facets (expected for a multi-facet step cut —
main + star/upper-girdle facets at nearby but not identical angles around
the stone), not a flat single plane per tier:

| Band | Reference | Recovered range | n facets | rms range (µm) |
|---|---|---|---|---|
| Crown | ≈ −58° | −59.19° … −54.24° | 9 | 4.8 – 6.0 |
| Pavilion tier 1 | ≈ +27° | +19.95° … +26.03° | 10 | 4.8 – 14.5 |
| Pavilion tier 2 | ≈ +39° | +34.66° … +40.62° | 8 | 4.8 – 5.2 |
| Pavilion tier 3 | ≈ +45° | +43.55° … +47.52° | 9 | 3.5 – 5.9 |
| Pavilion tier 4 | ≈ +50° | +49.55° … +53.47° | 4 | 4.9 – 5.6 |

The four-tier pavilion + single-band crown structure matches the az-74
reference qualitatively and the per-facet rms values (mostly 4.7–8 µm,
median 5.0 µm) match the reference's 4.7–8.0 µm range closely. The lowest
tier (~+20–26° vs reference +27°) is systematically ~1–5° shallower and has
the two worst-fit facets in the whole mesh (14.5 µm, 12.5 µm) — a plausible
signal that this tier (nearest the table/widest part of the stone) is where
the dimensional-fidelity error (G3) is concentrated, though this was not
independently confirmed. No spurious 19-step over-segmentation of a single
facet was observed — each band's facet count is a plausible one-per-real-facet
count for a step cut, not spec-noted micro-slicing artifacts.
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

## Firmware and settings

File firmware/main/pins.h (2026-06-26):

// firmware/main/pins.h
#pragma once
#include "driver/gpio.h"

#define PIN_STEP        GPIO_NUM_1
#define PIN_DIR         GPIO_NUM_2
#define PIN_ENABLE      GPIO_NUM_3
#define PIN_RGB_LED     GPIO_NUM_8   // onboard WS2812

#define DIR_ACTIVE_LEVEL    1        // DIR level for positive microsteps
#define ENABLE_ACTIVE_LEVEL 1        // level that energises the ADB-5331A
#define STEP_PULSE_US       3        // STEP high time (>= driver min, verify datasheet)

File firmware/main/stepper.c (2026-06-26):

// firmware/main/stepper.c
#include "stepper.h"
#include "pins.h"
#include "driver/gpio.h"
#include "driver/gptimer.h"
#include "esp_rom_sys.h"
#include "freertos/FreeRTOS.h"
#include "freertos/task.h"

static gptimer_handle_t s_timer;
static volatile unsigned s_total, s_index;
static volatile const ramp_profile_t *s_profile;
static volatile TaskHandle_t s_waiter;

// NOT IRAM_ATTR: default gptimer ISR runs from flash; callee helpers are flash-resident.
static bool on_alarm(gptimer_handle_t t, const gptimer_alarm_event_data_t *e, void *arg) {
    (void)t; (void)e; (void)arg;
    gpio_set_level(PIN_STEP, 1);
    esp_rom_delay_us(STEP_PULSE_US);
    gpio_set_level(PIN_STEP, 0);
    s_index++;
    BaseType_t hp = pdFALSE;
    if (s_index >= s_total) {
        gptimer_stop(t);
        vTaskNotifyGiveFromISR(s_waiter, &hp);
    } else {
        // auto-reload to 0 => alarm_count is the relative interval to the next step
        gptimer_alarm_config_t a = { .reload_count = 0, .alarm_count =
            ramp_interval_us((const ramp_profile_t *)s_profile, s_total, s_index), .flags.auto_reload_on_alarm = true };
        gptimer_set_alarm_action(t, &a);
    }
    return hp == pdTRUE;
}

void stepper_init(void) {
    gpio_config_t io = { .pin_bit_mask = (1ULL<<PIN_STEP)|(1ULL<<PIN_DIR)|(1ULL<<PIN_ENABLE),
                         .mode = GPIO_MODE_OUTPUT };
    gpio_config(&io);
    gpio_set_level(PIN_ENABLE, ENABLE_ACTIVE_LEVEL);
    gpio_set_level(PIN_STEP, 0);

    gptimer_config_t cfg = { .clk_src = GPTIMER_CLK_SRC_DEFAULT,
                             .direction = GPTIMER_COUNT_UP, .resolution_hz = 1000000 }; // 1 us tick
    gptimer_new_timer(&cfg, &s_timer);
    gptimer_event_callbacks_t cbs = { .on_alarm = on_alarm };
    gptimer_register_event_callbacks(s_timer, &cbs, NULL);
    gptimer_enable(s_timer);
}

void stepper_move_blocking(long microsteps, const ramp_profile_t *profile) {
    if (microsteps == 0) return;
    gpio_set_level(PIN_DIR, microsteps > 0 ? DIR_ACTIVE_LEVEL : !DIR_ACTIVE_LEVEL);
    esp_rom_delay_us(5);  // DIR setup time before first pulse
    s_total = (unsigned)(microsteps > 0 ? microsteps : -microsteps);
    s_index = 0;
    s_profile = profile;
    s_waiter = xTaskGetCurrentTaskHandle();

    gptimer_set_raw_count(s_timer, 0);
    gptimer_alarm_config_t a = { .reload_count = 0,
        .alarm_count = ramp_interval_us((const ramp_profile_t *)s_profile, s_total, 0), .flags.auto_reload_on_alarm = true };
    gptimer_set_alarm_action(s_timer, &a);
    gptimer_start(s_timer);
    ulTaskNotifyTake(pdTRUE, portMAX_DELAY);
}

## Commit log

2026-06-25 feat(fw): ASCII command parser with host tests
    Pure-C command_parser component parses ASCII line protocol verbs
    (STEP/MOVEDEG/SETV/SETACC/SETSETTLE/SETRES/HOME/STATUS) case-insensitively,
    validating integer/double args; yields CMD_BADARG/CMD_UNKNOWN on errors.
    6 host tests pass (TDD: RED confirmed on missing source, GREEN after impl).
2026-06-25 docs(plan-b): ESP-IDF 5.4 compatibility notes and glue-code fixes
    - console-vs-usb_serial_jtag-driver coexistence caveat (B6)
    - drop IRAM_ATTR from gptimer ISR callback (B5)
    - led_strip v2 LED_MODEL_WS2812 (B8)
    - LVGL 9.2 lv_display_get_screen_active + ST7789 panel gap (B8)
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2026-06-25 fix(fw): correct GPTimer re-arm to relative interval; volatile ISR state
    [stepper.c]
2026-06-25 docs(plan-b): fix Task 5 GPTimer re-arm to auto-reload relative interval
2026-06-25 feat(fw): command dispatch controller with OK/READY/STATUS protocol
    Adds controller.c/h implementing the full command-dispatch state machine:
    STEP/MOVEDEG/SETV/SETACC/SETSETTLE/SETRES/HOME/STATUS with OK→move→READY
    flow. Updates CMakeLists to include controller.c and add command_parser and
    motion_math deps. Sets app_main to integration wiring (stepper+usb_cdc+controller,
    no display). Build verified clean on ESP-IDF 5.4 / esp32c6; binary 0x2c190 bytes.
2026-06-26 feat(fw): RGB LED + ST7789/LVGL status display
    Add status_display module: WS2812 RGB LED (led_strip RMT) + 172x320
    ST7789 LCD via LVGL 9.2 / esp_lvgl_port. Controller emits ST_MOVING /
    ST_SETTLING / ST_IDLE on each do_move phase; app_main calls
    status_display_init() first.
    API compat fix: esp_lvgl_port 2.8.0 references LV_COLOR_FORMAT_RGB565_SWAPPED
    (added in LVGL 9.3); patched managed component with a #ifndef shim mapping
    it to LV_COLOR_FORMAT_RGB565 for LVGL 9.2.2.
    Resolved components: lvgl/lvgl 9.2.2, espressif/esp_lvgl_port 2.8.0~1,
    espressif/led_strip 2.5.5
    [status_display.c]
2026-06-26 fix(fw): pin LVGL/esp_lvgl_port to a compatible pair (drop managed_components patch)
    Bump lvgl/lvgl from ~9.2.0 to ~9.3.0 so the resolved pair
    (lvgl 9.3.0 + esp_lvgl_port 2.8.0~1) is natively compatible.
    LV_COLOR_FORMAT_RGB565_SWAPPED is present in LVGL 9.3+; no patch
    to managed_components is needed. Build verified clean from pristine
    re-downloaded components.
2026-06-26 fix(fw): drive LCD backlight (GPIO22) and add init error checks
    [status_display.c]
2026-06-26 feat(fw): LCD backlight via LEDC PWM at 50% brightness
    Replace digital GPIO22 high with LEDC (low-speed, 8-bit, 5kHz) at 50% duty;
    brightness adjustable via LCD_BL_DUTY_PCT.
    [status_display.c]
2026-06-26 fix(fw): swap RGB565 bytes for ST7789 LCD (removes text colour fringe)
    [status_display.c]
2026-06-26 fix(fw): correct onboard LED R/G swap (board is RGB, WS2812 model is GRB)
    led_strip 2.5.5 lacks color_component_format; swap R<->G in led_set instead.
    [status_display.c]
2026-06-26 docs(fw): firmware README (protocol, wiring, build/flash, host tests)
2026-06-26 docs: align protocol grammar with single-threaded controller (state=idle, drop ERR busy)
2026-06-26 chore: stop tracking .superpowers/ scratch (briefs, reports, ledger)
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2026-06-26 feat: calibration math (axis fit, scale, steps-per-rev) and persistence
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2026-06-26 feat: bench scan pipeline (config -> calibrate -> prescan -> scan -> reconstruct -> view)
2026-06-29 feat(camera): GenTL/Harvesters backend for legacy Baumer EXG50 (neoAPI unsupported)
2026-06-29 docs(camera): EXG50 GenICam feature reference; example exposure for no-light bench
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2026-07-03 feat(scan): holder masking, Taubin smoothing, and CLI -m fix for bench scans
    Enable clean end-to-end scans of a gem on a pedestal on the real EXG50 rig.
    - fix(cli): add a __main__ guard so `python -m gemscanner.cli ...` actually
    runs. The documented invocation previously imported the module and exited
    silently without calling main().
    - feat: thread holder_mask_rows through prescan, run_scan, and the
    calibrate_axis / check_fov / _common bench scripts (+ config scan.holder_mask_rows),
    masking the full-width stage + pedestal below the gem out of the silhouette.
    Without it the stage corrupts the axis-centroid fit, forces the FoV check to
    always report a border touch, and gets recons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
2026-07-04 fix(motion): settle after opening the serial port
    The ESP32-C6's USB-CDC resets / re-enumerates when the port is opened, so the
    board isn't ready for ~1-2 s after serial.Serial(...) returns. The first command
    (e.g. SETRES) was dropped and raised StageError "timeout waiting for reply".
    SerialTransport now waits settle_s (default 2.0) and flushes the input/output
    buffers before returning, so scans work on a freshly reset board.
    [transport.py]
2026-07-04 docs(gui): design spec for PySide6 GUI over the CLI
    Guided per-gem wizard (align/exposure preview, holder-mask, axis
    calibrate, scan, reconstruct) with a batch queue. Wraps existing
    library code; CLI stays additive.
2026-07-04 docs(gui): implementation plan for the PySide6 GUI
    10 TDD tasks: project model, frame analysis, probe_axis refactor,
    ScanController progress/cancel, ScanSession, HardwareWorker thread,
    preview/queue/wizard widgets, MainWindow + dark QSS + gui CLI command.
2026-07-04 refactor(calibration): extract probe_axis; share with calibrate_axis script
    Extracted the inline axis-probe loop from scripts/calibrate_axis.py:main into a reusable library function probe_axis(...) with progress and cancel hooks. The script now calls the shared function via 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
    - Created gemscanner/calibration/axis_probe.py::probe_axis() with progress/cancel support
    - Removed unused imports (numpy, extract_silhouette, fit_rotation_axis) from calibrate_axis.py
    - Rewired calibrate_axis.py to call probe_axis() instead of inline loop
    - Added tests (test_probe_axis_fits_center_with_progress, test_probe_axis_cancel_stops_early)
    - All 64 tests pass; script verifie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
2026-07-04 feat(gui): ScanSession service layer wrapping camera+stage ops
    - Implement Qt-free ScanSession class that owns camera + stage
    - Expose operations for calibrate, scan, reconstruct workflows
    - Enable dependency injection for headless testing with SceneCamera+FakeFirmware
    - All 68 tests pass
2026-07-04 feat(gui): HardwareWorker thread for preview polling and off-UI ops
2026-07-04 feat(gui): QueuePanel and WizardPanel for the guided batch flow
2026-07-04 fix(gui): update worker mask on gem switch; self-heal preview on error; drop unused imports
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2026-07-05 fix(gui): guard end-of-queue Next gem; tighten controls/wizard tests
    Increment review Minor fixes: _on_next_gem no longer resets the wizard
    to Mount when there is no next gem; assert programmatic slider set does
    not emit; cover the maskChanged->Holder-mask step transition.
2026-07-06 feat(reconstruction): facet-preserving de-terracing + soft-hull method, selectable in GUI
    Horizontal strike-lines were a reconstruction artifact of independent per-row
    carving (verified: gem04 silhouette edge is clean/sharp; not edge noise or stray
    light). Add three facet-preserving options, chosen by median rank-rejection of
    per-row outliers (bilateral/TV/mesh-Laplacian all fail: blur facets or keep noise):
    - edge_median_rows: median-smooth silhouette L/R per view (image space, best
    visual; gem04 terracing 68->3um, volume impact <=+0.24%, dims unchanged)
    - axial_median_rows: median-smooth ring radius field along z (mesh space, cheapest)
    - method="soft_hull": anti-aliased volumetric visua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
2026-07-06 docs: rewrite README for GitHub (GUI, reconstruction methods, GenTL camera)
    Adds the PySide6 GUI workflow and the selectable reconstruction methods
    (edge/axial median de-terracing + soft hull), corrects the camera backend notes
    to GenTL/Harvesters, and refreshes install/deps. Includes the terracing figure.
2026-07-11 docs(reconstruction): design for unsupervised faceted-gem reconstruction
    Recover facet planes from the turntable support function (affine-in-z tangent
    support), intersect half-spaces into a clean convex polytope -> flat facets,
    sharp edges, exact meet-points, no terracing. Hybrid seed (Gauss-sphere on
    soft-hull) + exact refit on raw silhouette tangents. New method="facet".
2026-07-11 docs(reconstruction): implementation plan for faceted-gem method
    9-task TDD plan, synthetic-GT-first: polyhedron silhouette generator, toy-gem
    ground truth, support-map extraction, affine plane-recovery math, Gauss-sphere
    seeding, half-space assembly (FacetReconstructor), pipeline+GUI wiring, gem04
    validation.
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2026-07-11 feat(reconstruction): plane recovery + half-space assembly (FacetReconstructor)
    Adds recover_planes/_merge_planes/_nearest_view/_interior_point/planes_to_polytope
    and FacetReconstructor to facet_fit.py, plus facet_* params on ReconstructionParams.
    Two fixes beyond the brief's literal template were required to hit the <1deg
    end-to-end tolerance: (1) restrict each seed's affine fit to its own z-extent
    (annotate_seed_z_extent) since a raw support column mixes girdle/crown/pavilion
    tiers with different slopes over the object's full height; (2) pick the
    nearest-to-seed-azimuth valid view rather than the window's minimum-RMS view,
    since Theil-Sen's discrete slope plateaus can tie or even favour a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
2026-07-12 test(reconstruction): validate faceted method on gem04 real scan
    Facet recovery succeeds on the real gem04 scan (43 facets, watertight,
    median per-facet fit residual 32.8um beating the 68um terracing baseline)
    but is only dimensionally faithful to gem.stl within a few hundred um
    (+5-6% X/Y, +2.7% Z), not the few tens of um hoped for, and ~27% of
    facets exceed the terracing baseline (worst 165.8um). Also documents a
    real gap found along the way: gem04's manifest doesn't carry
    holder_mask_rows, so reconstructing without it silently includes the
    pedestal post and blows dimensions up ~5x under every method (strip,
    soft_hull, facet alike) -- not a facet-specific bug. Swept
    facet_merge_deg/facet_m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
2026-07-12 refactor(reconstruction): final-review cleanups
    Thread per-facet rms into metadata["facets"] (reproducible validation), drop
    unused `import math` in support.py, remove unused facet_planarity_tol_mm param,
    document the full-360-degree scan assumption in support_maps. Full suite 110 green.
2026-07-12 docs(reconstruction): facet detection v2 design — segment raw H(z), no soft-hull seed
    Root cause of v1 failure on gem04: soft-hull seed rounds facets away before
    detection; culet capped flat (scans are culet-up). v2: per-view affine
    segmentation of raw support fn (~5um on gem04 spike) + cross-view clustering,
    orientation-aware table/culet. Back-end (refit, half-space assembly) retained.
2026-07-12 docs(plan): facet detection v2 — 5-task plan (segment, chain, table, rewire, gem04 visual gate)
2026-07-12 docs(plan): v2 Task 2 — bidirectional chain extension (forward-only splits wrapped arcs)
    Verified numerically: forward-only chaining from a mid-arc seed misses the
    views before it (fixture {10,11,0,1,2} split to {0,1,2}). Fixed version
    passes both prescribed tests.
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2026-07-13 docs: v2.1 detection amendment (user-approved) — slice-edge azimuths replace chain clustering
    Pre-verification: chains conflate facet and arris traces (toy gate FAIL 2.5deg);
    slice-edge azimuth families + per-azimuth tier segmentation PASS (0.338deg,
    +2.97% vol); gem04 az74 tiers fit at 4.7-8um rms (spike's 19-step ladder was
    over-segmentation). Params: +facet_min_edge_mm, seg window 17; -min_views/slope_tol.
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2026-07-13 feat(reconstruction): v2.3 — girdle-band recovery + two-scale tiers + extended azimuth bands
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2026-07-14 docs(spec): ESP32-C6 status display redesign — minimalist dark theme
2026-07-14 docs(plan): ESP32-C6 status display redesign implementation plan
2026-07-14 feat(fw): redesign status LCD — minimalist dark theme, colored state word
    [status_display.c]
2026-07-14 docs(fw): document redesigned status display + fmt_num component
    Update the firmware README for the minimalist dark-theme LCD: per-state
    palette table (OFFLINE/READY/ROTATING/SETTLING + accent colours), LED now
    lit in the state accent, new screen layout description, Montserrat 20/28,
    and add fmt_num to the components/host-test coverage lists.
2026-07-23 docs(plan): clean-room silhouette->facet bake-off implementation plan
    8 tasks: support-sample front-end + synthetic generator, shared
    polytope back-end, objective strike-line metric, three candidate
    recoverers (EGI / RANSAC / dual-convex) each gated on a synthetic
    bipyramid, gem04 bake-off harness + PIL render, results note.
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2026-07-23 feat(cleanroom): candidate C — EGI/Gauss-sphere facet recovery
    Fixes a geometric flaw in the naive per-column dh/dz -> normal mapping:
    that only gives the true facet normal when a view's azimuth exactly
    matches a facet's own normal direction; every other column tracks the
    shared edge with the neighboring facet (a support-function vertex),
    producing a smooth wrong-normal continuum between true facets rather
    than 12 tight clusters (verified: median per-sample error 10.4 deg,
    merge_planes fragmented to 20 facets).
    Fix: filter candidate normals to azimuth columns where |dh/dz| is a
    local minimum across the circular azimuth axis at each z-row — true
    facet azimuths are kinks (one-sided deriva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
2026-07-23 feat(cleanroom): gem04 bake-off harness + PIL comparison render
    Runs the 3 clean-room candidates (RANSAC, dual/hull, EGI) alongside the
    shipped strip-intersection control and v2.3 facet benchmark on the real
    gem04 scan. All three candidates produce watertight meshes after
    retuning rms_tol_mm 0.15->0.7 (synthetic-fixture default rejects nearly
    everything on real sensor noise). Strike-line energy cleanly separates
    the space-carving control (6.8um) from every faceted method (0.0um),
    confirming the central hypothesis of the clean-room investigation. All
    three candidates lose the girdle facet band on real data (0 near-
    vertical facets vs ~3% in ground truth) and are 10-100x less accurate
    in exten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
    [cand_a_gem04.stl, cand_b_gem04.stl, cand_c_gem04.stl]
2026-07-23 docs(cleanroom): final-review corrections — gem.stl reproduction proof, rmsMed caveat, retune cause
    Apply five documentation-correctness fixes from the whole-branch review to
    the bake-off results note: replace the weak V=F/2+2 vertex-count argument
    with an exact Taubin-smoother reproduction proof for gem.stl's provenance;
    caveat the rmsMed column against v2.3's incomparable 5um facet-RMS figure;
    correct the stated cause of the 0.15->0.7 rms_tol_mm retune (facet_rms's
    column-averaging construction, not silhouette noise); tighten "10-100x less
    accurate" to the axis-dependent "2x-115x"; and inline the tolerance-sweep
    table so it survives the git-ignored working artifacts it was drawn from.
    Al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
2026-07-23 feat(recon): sub-pixel silhouette edge localisation, on by default
    Place each silhouette edge on its intensity crossing (linear interp
    between the bracketing pixel pair) instead of the nearest whole column,
    attacking terracing at its source rather than denoising after. gem04:
    per-row edge roughness 12.6->2.2um (-83%), mean shift only +0.43um
    (anti-aliased edges + mid-ramp Otsu keep the crossings symmetric).
    - vision/silhouette.py: row_spans_subpixel, extract_silhouette_with_threshold,
    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
